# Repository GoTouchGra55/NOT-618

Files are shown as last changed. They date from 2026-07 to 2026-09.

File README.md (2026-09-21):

# NOT-618

_A custom CoreXY printer built on hopes and dreams._

   

**New Object Transmitter-618 / NOT-618** is a medium sized print volume _(220 × 220 × 220 mm)_ custom CoreXY 3d printer developed as a long term engineering project.

The project focuses on reliability, serviceability, and my open-source loyalty while serving as a platform for learning embedded systems, mechanical & PCB design, and firmware engineering.

## Features

- Automatic bed-leveling using BLTouch
- Independent dual Z motors
- Custom STM32F407-based controller (Vulcan-MK1)
- Marlin firmware support
- Fully open source design
- 24V power input

## Mechanical Design

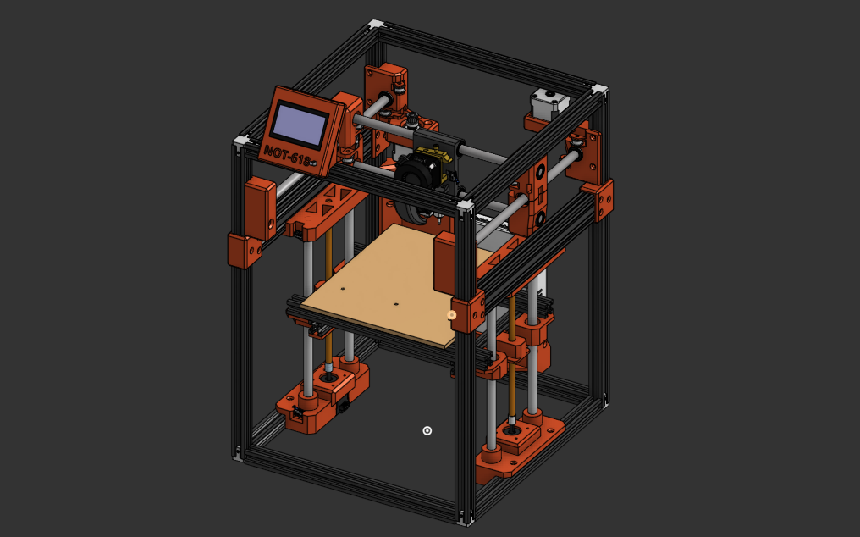
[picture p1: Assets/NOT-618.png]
NOT-618


### CAD: [OnShape URL](https://cad.onshape.com/documents/e82edfc86bb0a1665cdc75ee/w/ca3abfddd82f0954c06884bb/e/6fbd4bded61cf9b65a4d5030)

## PCB Design _(Vulcan-MK1)_

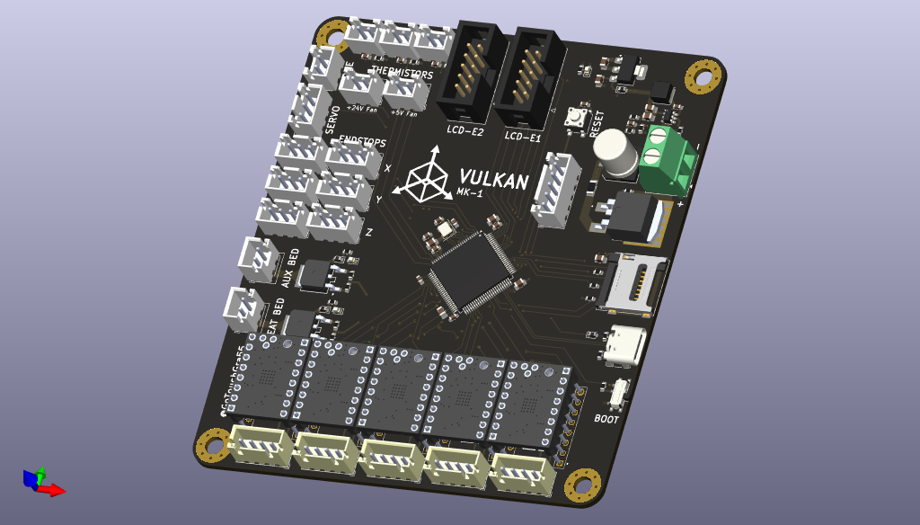
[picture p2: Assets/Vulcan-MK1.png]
Vulcan-MK1


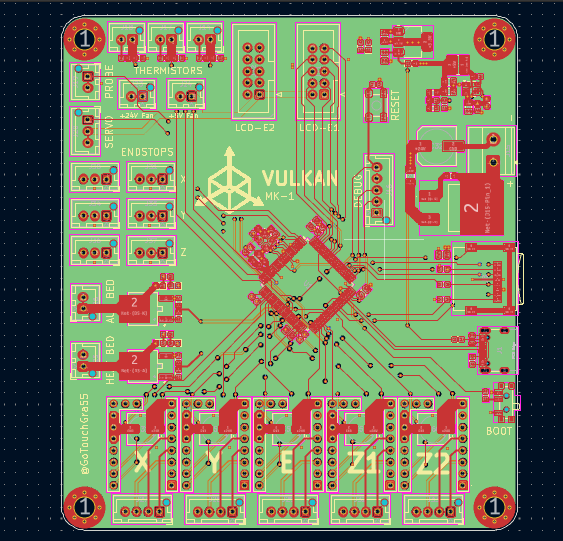
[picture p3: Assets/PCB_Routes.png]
Vulcan-MK1 Routes


For GERBER file see [Vulcan-MK1](PCB/production/Vulcan-MK1.zip)

## Schematics

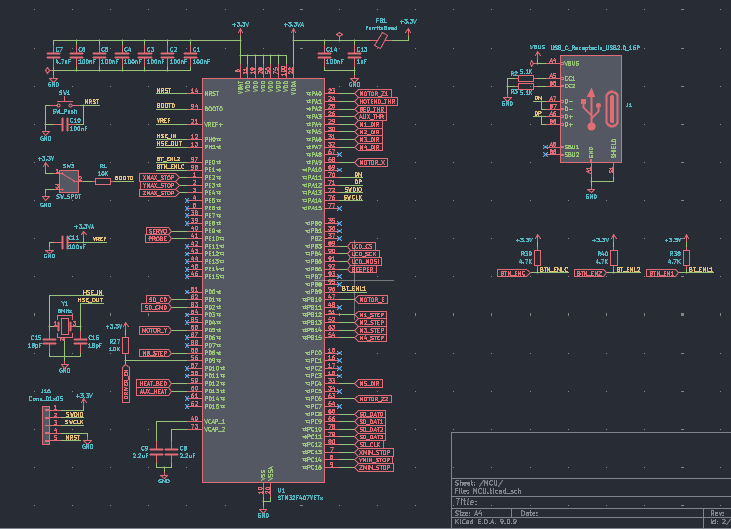
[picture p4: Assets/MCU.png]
MCU

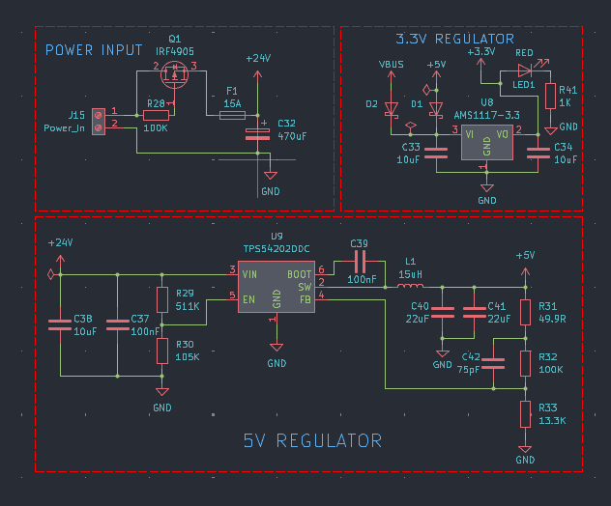
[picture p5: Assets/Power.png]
POWER

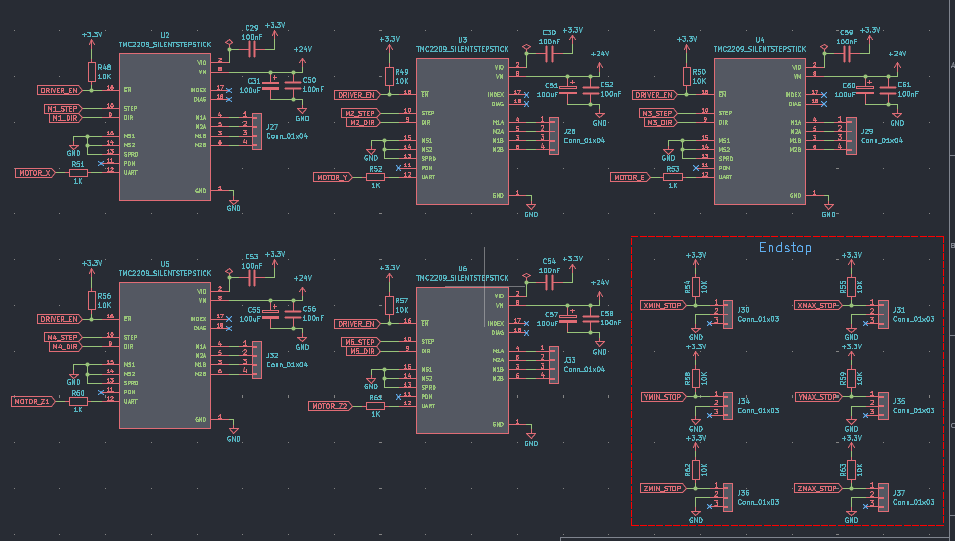
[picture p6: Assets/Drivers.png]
Drivers

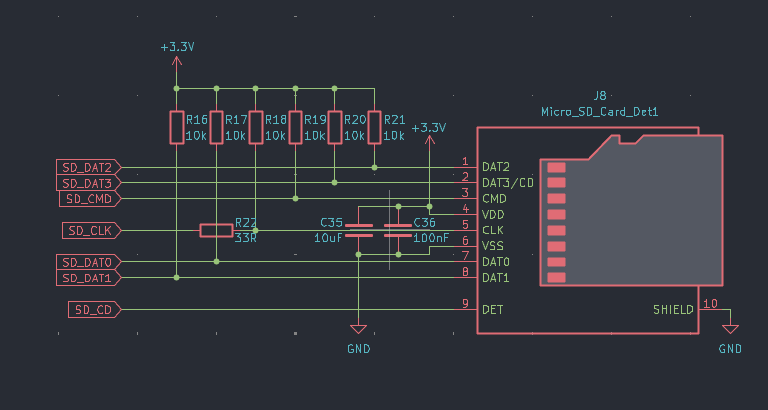
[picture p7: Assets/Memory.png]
Memory

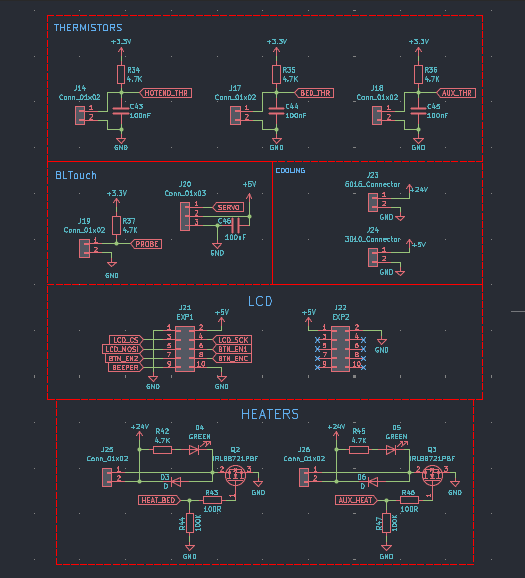
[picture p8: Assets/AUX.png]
Aux


## Specifications

| Component | Specification |
| --- | --- |
| Motion System | CoreXY |
| Build Volume | 220 × 220 × 220 mm |
| MCU | STM32F407VET6 |
| Stepper Drivers | TMC2209 |
| Hotend | E3D V6 |
| Heated Bed | Anycubic Kobra Go 24V |
| Bed Probe | BLTouch |
| Power Supply | 24V 15A |
| Cooling | 5015 Part Cooling + 3010 Hotend Fan |

## Assembly guide

1. Refer to the Onshape assembly for component placement and assembly order.
2. Do not carelessly wire the pcb and ensure good solder joints.

## ⚠️ Warning

1. Double-check polarity of capacitors and power input before powering the board. Otherwise you've made a fancy bomb :D
2. Use a 24v 15A SMPS for optimal performance. NEVER go higher than this.

## Flashing the Firmware

### 1. Build the Firmware

Compile Marlin using PlatformIO:

```bash
pio run -e STM32F407VE_black
```

After a successful build, the firmware will be located at:

```
.pio/build/STM32F407VE_black/firmware.bin
```

---

### 2. Copy the Firmware

1. Insert a microSD card (FAT32 formatted).
2. Copy `firmware.bin` to the root directory of the SD card.

The directory should look like:

```
/
├── firmware.bin
```

### 3. Flash the Board

1. Turn **off** the printer.
2. Insert the microSD card into the onboard SD card slot.
3. Power the board.

The STM32 bootloader will automatically detect `firmware.bin` and begin flashing.

Do **not** remove power during this process.

---

### 4. Verify the Flash

After flashing is complete:

- The board should boot into Marlin.
- Connect to the USB serial port.
- Send:

```gcode
M115
```

A successful response should report the installed Marlin version.

## Bill of Materials

| Name | Purpose | Quantity | Total Cost (USD) | Distributor |
| --- | --- | ---: | ---: | --- |
| Zip Ties | Cable management | 1 | $1.04 | Daraz Nepal |
| 22 AWG Wire | For long connections | 1 | $4.08 | Daraz Nepal |
| 18 AWG Wire | For power connections | 1 | $5.34 | Daraz Nepal |
| 24V 15A SMPS | For power delivery | 1 | $31.14 | Daraz Nepal |
| 0603 resistors | For PCB | 1 | $4.58 | Daraz Nepal |
| 0805 capacitors | For PCB | 1 | $5.78 | Daraz Nepal |
| Pitch Connectors | For PCB | 1 | $6.12 | Daraz Nepal |
| JST XH Connectors | For PCB | 1 | $5.11 | Daraz Nepal |
| 5015 24V Fan | For cooling duct | 1 | $5.27 | Daraz Nepal |
| Screws | For securing connections | 1 | $11.78 | Daraz Nepal |
| 24V Heated Bed | For printer | 1 | $19.78 | Daraz Nepal |
| PEI Sheet | For printer | 1 | $13.52 | Daraz Nepal |
| GT2 idler | For movement | 8 | $25.24 | Daraz Nepal |
| GT2 belt | For movement | 1 | $10.99 | Daraz Nepal |
| E3D Hotend | For printing | 1 | $11.05 | Daraz Nepal |
| Timing belt fixer | For attaching belts | 1 | $3.1 | Daraz Nepal |
| T-Nuts | For attaching extrusions | 1 | $5.84 | Daraz Nepal |
| MK8 Extruder | For filament output | 1 | $12.14 | Daraz Nepal |
| Pancake Stepper | For MK8 extruder | 1 | $12.04 | Daraz Nepal |
| 3015 Fan | For hotend cooling | 1 | $3.14 | Daraz Nepal |
| Brass Inserts | For fasteners | 1 | $8.89 | Daraz Nepal |
| Allen Keys | For securing hex nuts | 1 | $1.75 | Daraz Nepal |
| Limit switches | For min-max feedback | 2 | $3.92 | Daraz Nepal |
| Motor Coupler | For attaching steppers and rods | 2 | $2.44 | Daraz Nepal |
| Threaded Rods | For Z-axis movement | 2 | $7.54 | Daraz Nepal |
| GT2 pulley | For steppers | 2 | $1.57 | Daraz Nepal |
| Stepper Motors | For movement | 4 | $51.95 | Daraz Nepal |
| LM10UU Bearings | For linear movement | 8 | $18.49 | Daraz Nepal |
| LM12UU Bearings | For linear movement | 4 | $11.99 | Daraz Nepal |
| Linear Shaft (300mm) | For linear movement (12mm) | 4 | $67.98 | Daraz Nepal |
| Linear Shaft (500mm) | For linear movement (10mm) | 2 | $27.06 | Daraz Nepal |
| Linear Shaft (330mm) | For linear movement (10mm) | 2 | $19.10 | Daraz Nepal |
| BLTouch | For auto-bed leveling | 1 | $12.74 | Daraz Nepal |
| 2040 Extrusion | For printer stability | 1 | $15 | Daraz Nepal |
| 2020 Extrusion (800mm) | Printer frame | 5 | $117.08 | Daraz Nepal |
| 2020 Extrusion (600mm) | Printer frame | 5 | $104.98 | Daraz Nepal |
| TMC2209 drivers | To drive motors | 5 | $37.26 | Daraz Nepal |
| 12864 LCD | To display stuff | 1 | $35.39 | Daraz Nepal |
| 3-Way Connector | To connect corners of extrusion | 8 | $17.53 | Daraz Nepal |
| Vulcan-MK1 PCB | To control printer | 1 | $151.24 | JLCPCB |
| **Shipping** | | | **$29.72** | **Daraz Nepal & JLCPCB** |
| **Total** | | | **$944.16** | |

## License

### MIT-License - See [LICENSE](/LICENSE)

## Author 🧑‍💻

### [Shaurya Tamang](https://shauryatamang.netlify.app/)

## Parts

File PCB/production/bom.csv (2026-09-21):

Designator | Footprint | Quantity | Value | LCSC Part #
C1, C10, C11, C12, C14, C18, C2, C29, C3, C30, C36, C4, C43, C44, C45, C46, C5, C50, C52, C53, C54, C56, C58, C59, C6, C61 | 0603 | 26 | 100nF
C13 | 0805 | 1 | 1uF
C15, C16 | 0603 | 2 | 18pF
C17, C33, C34, C35 | 0805 | 4 | 10uF
C19, C20 | 0805 | 2 | 22uF
C21 | 0603 | 1 | 75pF
C31, C51, C55, C57, C60 | CP_Elec_6.3x7.7 | 5 | 100uF
C32 | C_Elec_8x10.2 | 1 | 470uF
C7 | 0805 | 1 | 4.7uF
C8, C9 | 0805 | 2 | 2.2uF
D1, D2 | 0603 | 2 | D_Schottky
D3, D6 | 0603 | 2 | D
D4, D5 | 0603 | 2 | GREEN
F1 | 1206 | 1 | 15A
FB1 | 0603 | 1 | FerriteBead
J1 | USB_C_Receptacle_GCT_USB4105-xx-A_16P_TopMnt_Horizontal | 1 | USB_C_Receptacle_USB2.0_16P
J14, J17, J18, J19, J25, J26 | JST_XH_B2B-XH-AM_1x02_P2.50mm_Vertical | 6 | Conn_01x02
J15 | TerminalBlock_Phoenix_MKDS-1,5-2-5.08_1x02_P5.08mm_Horizontal | 1 | Power_In
J16 | JST_XH_B5B-XH-AM_1x05_P2.50mm_Vertical | 1 | Conn_01x05
J20, J30, J31, J34, J35, J36, J37 | JST_XH_B3B-XH-AM_1x03_P2.50mm_Vertical | 7 | Conn_01x03
J21 | IDC-Header_2x05_P2.54mm_Vertical | 1 | EXP1
J22 | IDC-Header_2x05_P2.54mm_Vertical | 1 | EXP2
J23 | JST_XH_B2B-XH-AM_1x02_P2.50mm_Vertical | 1 | 5015_Connector
J24 | JST_XH_B2B-XH-AM_1x02_P2.50mm_Vertical | 1 | 3010_Connector
J27, J28, J29, J32, J33 | JST_XH_B4B-XH-AM_1x04_P2.50mm_Vertical | 5 | Conn_01x04
J8 | microSD_HC_Wuerth_693072010801 | 1 | Micro_SD_Card_Det1
L1 | L_Cenker_CKCS4030 | 1 | 15uH
LED1 | 0603 | 1 | RED
Q1 | TRANS_IRF3205S | 1 | IRF4905
Q2, Q3 | TO252_AOS | 2 | IRLB8721PBF
R1, R16, R17, R18, R19, R20, R21, R27, R48, R49, R50, R54, R55, R56, R57, R58, R59, R62, R63 | 0603 | 19 | 10K
R2, R3 | 0603 | 2 | 5.1K
R22 | 0603 | 1 | 33R
R28, R44, R47, R7 | 0603 | 4 | 100K
R34, R35, R36, R37, R38, R39, R40, R42, R45 | 0603 | 9 | 4.7K
R4 | 0603 | 1 | 511K
R41, R51, R52, R53, R60, R61 | 0603 | 6 | 1K
R43, R46 | 0603 | 2 | 100R
R5 | 0603 | 1 | 105K
R6 | 0603 | 1 | 49.9R
R8 | 0603 | 1 | 13.3K
SW1 | SW_SPST_PTS647_Sx38 | 1 | SW_Push
SW3 | SW_SPDT_PCM12 | 1 | SW_SPDT
U1 | LQFP-100_14x14mm_P0.5mm | 1 | STM32F407VETx
U2, U3, U4, U5, U6 | MODULE_TMC2209_SILENTSTEPSTICK | 5 | TMC2209_SILENTSTEPSTICK
U7 | SOT-23-6 | 1 | TPS54202DDC
U8 | SOT-223-3_TabPin2 | 1 | AMS1117-3.3
Y1 | Crystal_SMD_3225-4Pin_3.2x2.5mm | 1 | 8MHz

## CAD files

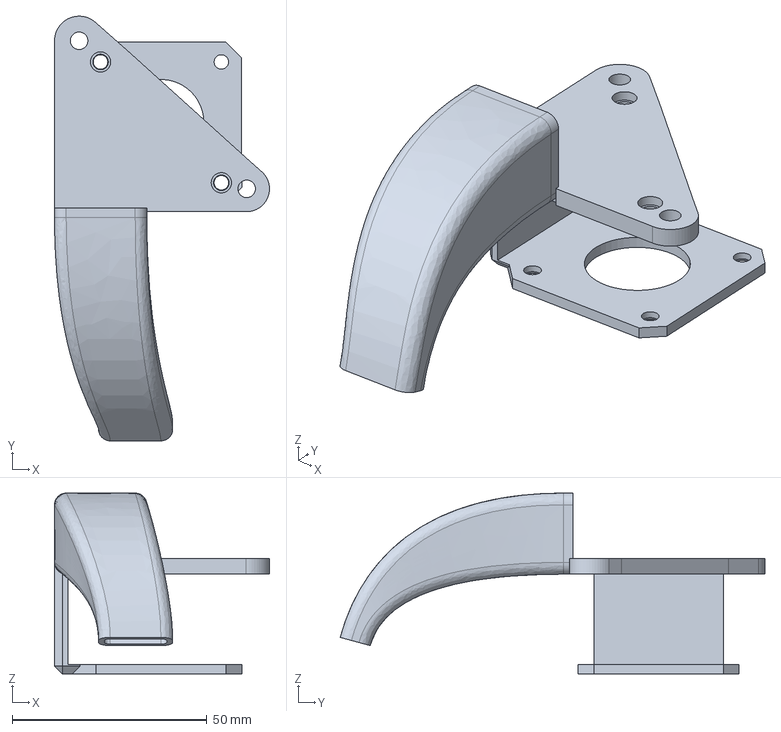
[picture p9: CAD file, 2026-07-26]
3d Files/STEP/NOT-618 - Duct Mount.step
55.2 x 109.0 x 46.4 mm

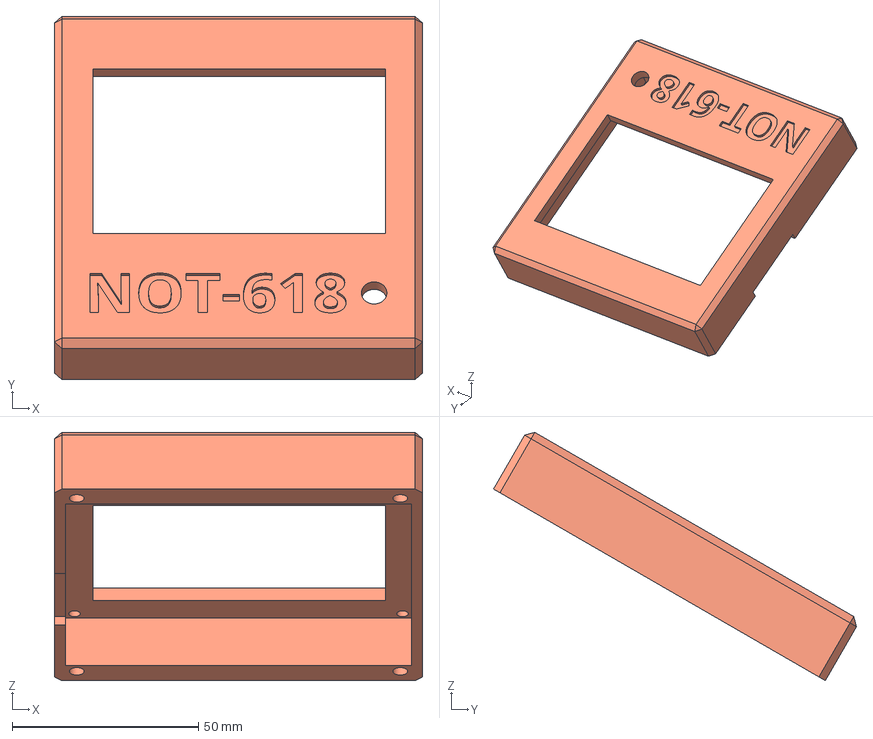
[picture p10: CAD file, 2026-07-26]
3d Files/STEP/NOT-618 - LCD Front.step
98.7 x 97.3 x 66.6 mm

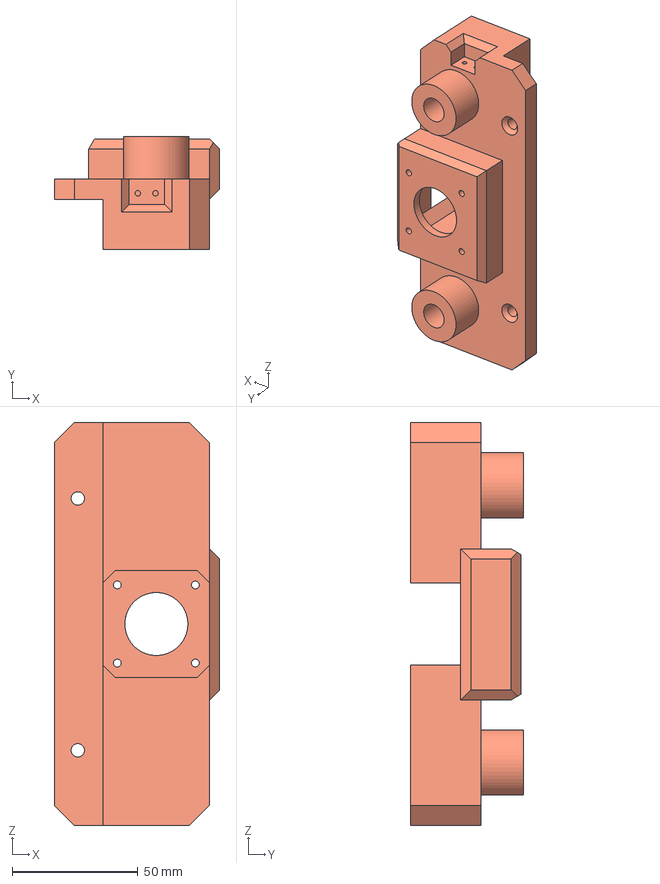
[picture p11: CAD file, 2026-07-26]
3d Files/STEP/NOT-618 - Z-BaseMount.step
65.7 x 45.0 x 160.0 mm

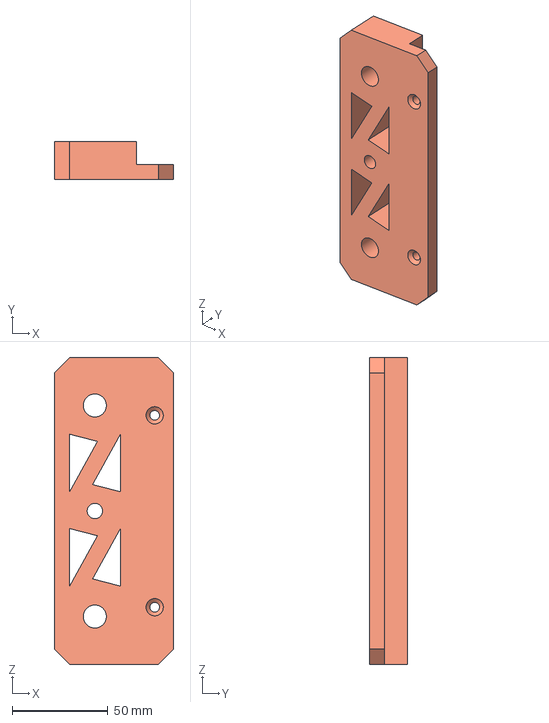
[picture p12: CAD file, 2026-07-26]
3d Files/STEP/NOT-618 - Z-TopMount.step
62.3 x 20.0 x 160.0 mm

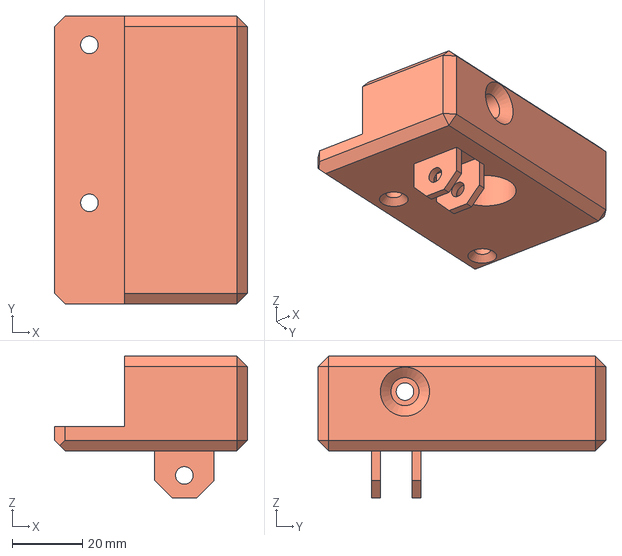
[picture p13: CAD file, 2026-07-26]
3d Files/STEP/NOT-618 - TFL-Rod Mount.step
55.0 x 82.0 x 40.4 mm

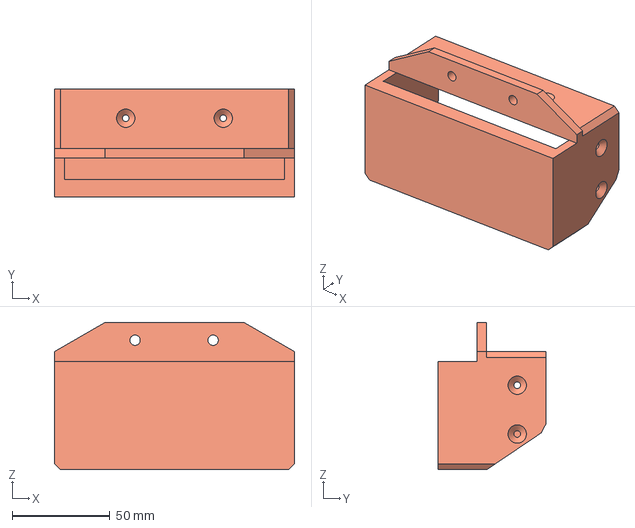
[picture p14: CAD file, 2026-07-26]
3d Files/STEP/NOT-618 - SMPS_Holder.step
123.0 x 55.4 x 75.5 mm

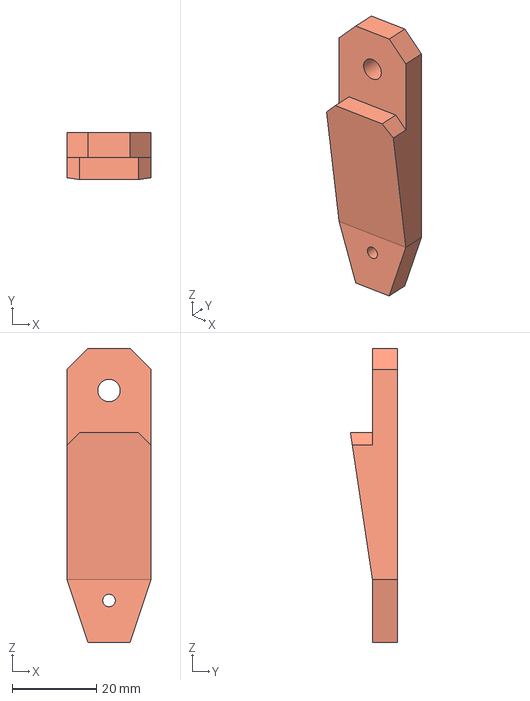
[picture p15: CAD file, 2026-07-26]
3d Files/STEP/NOT-618 - Bed Adapter.step
20.0 x 11.2 x 70.0 mm

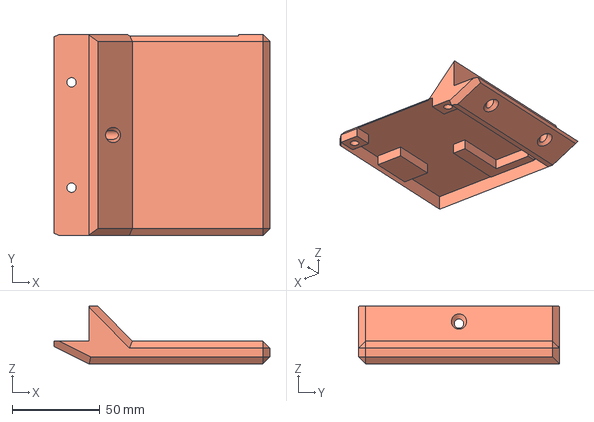
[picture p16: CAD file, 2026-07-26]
3d Files/STEP/NOT-618 - PCB_Holder.step
123.0 x 114.5 x 33.0 mm

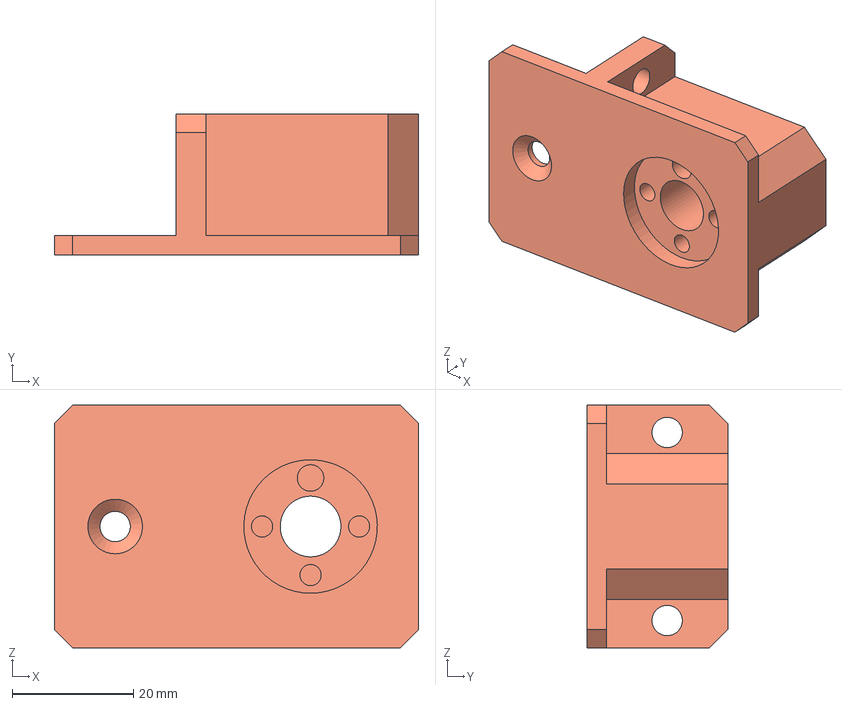
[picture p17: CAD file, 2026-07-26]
3d Files/STEP/NOT-618 - Lead Adapter.step
60.0 x 23.2 x 40.0 mm

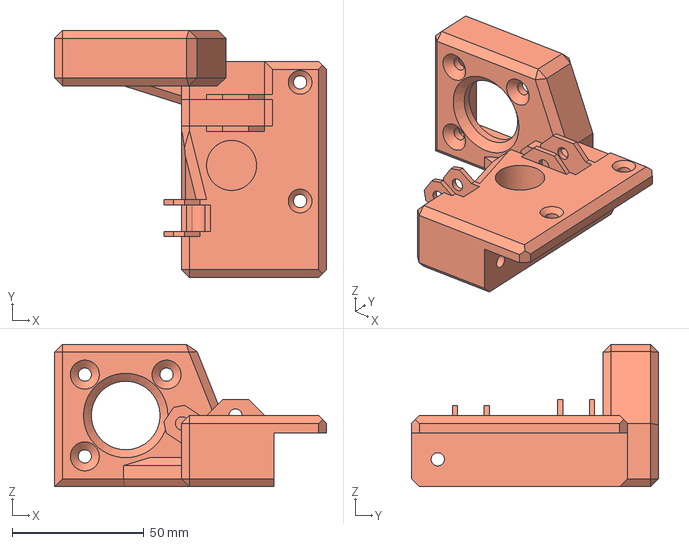
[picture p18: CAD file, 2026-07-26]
3d Files/STEP/NOT-618 - TBR-Rod Mount.step
103.1 x 93.8 x 54.0 mm

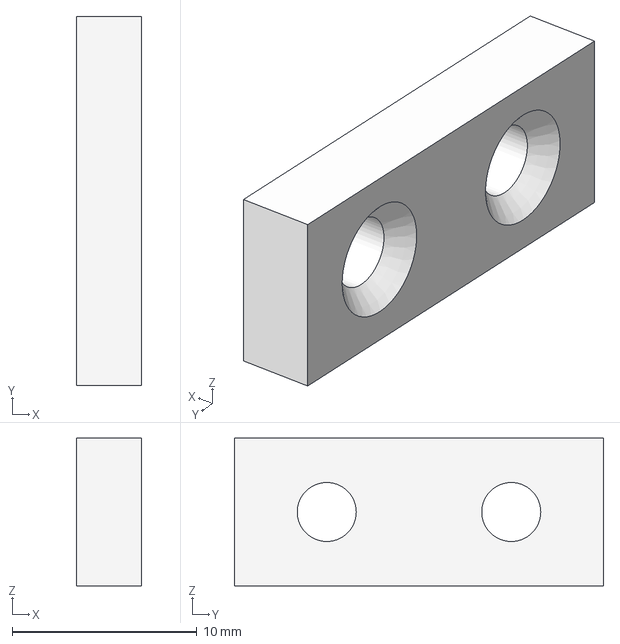
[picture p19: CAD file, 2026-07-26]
3d Files/STEP/NOT-618 - XY Mount.step
3.50 x 20.0 x 8.00 mm

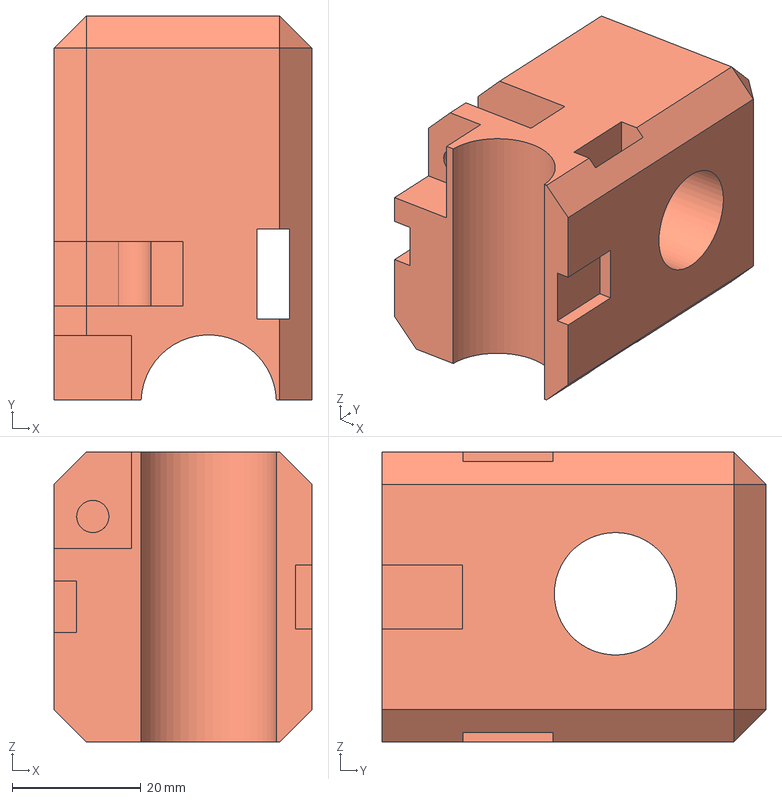
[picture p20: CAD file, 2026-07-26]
3d Files/STEP/NOT-618 - XY1_TOP.step
40.0 x 59.6 x 45.0 mm

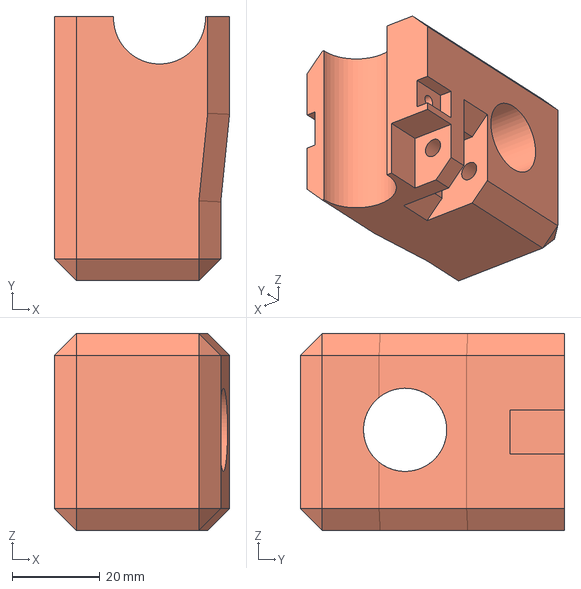
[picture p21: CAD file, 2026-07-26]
3d Files/STEP/NOT-618 - XY1_BOT.step
40.0 x 60.4 x 45.0 mm

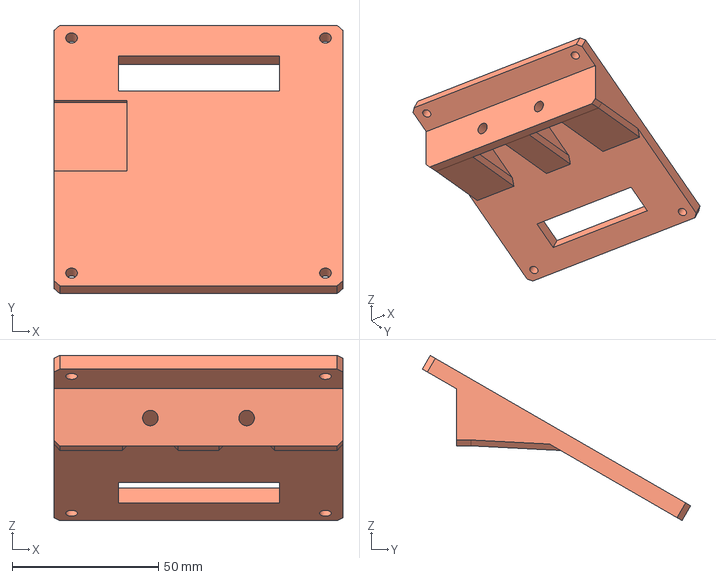
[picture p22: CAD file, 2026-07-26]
3d Files/STEP/NOT-618 - LCD Back.step
98.7 x 91.7 x 56.4 mm

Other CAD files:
3d Files/STEP/NOT-618 - Extruder Mount.step
3d Files/STEP/NOT-618 - XY2_BOT.step
3d Files/STEP/NOT-618 - TFR-Rod Mount.step
3d Files/STEP/NOT-618 - Ext Connector.step
3d Files/STEP/NOT-618 - Bearing Mount.step
3d Files/STEP/NOT-618 - Bed Adapter (1).step
3d Files/STEP/NOT-618 - Bed Adapter (2).step
3d Files/STEP/NOT-618 - Bed Adapter (3).step
3d Files/STEP/NOT-618 - Ext Connector (1).step
3d Files/STEP/NOT-618 - Ext Connector (2).step
3d Files/STEP/NOT-618 - Ext Connector (3).step
3d Files/STEP/NOT-618 - Lead Adapter (1).step
3d Files/STEP/NOT-618 - Linear Adapter (1).step
3d Files/STEP/NOT-618 - Linear Adapter (2).step
3d Files/STEP/NOT-618 - Linear Adapter (3).step
3d Files/STEP/NOT-618 - Linear Adapter.step
3d Files/STEP/NOT-618 - TBL-Rod Mount.step
3d Files/STEP/NOT-618 - XY Mount (1).step
3d Files/STEP/NOT-618 - XY2_TOP.step
3d Files/STEP/NOT-618 - Z-BaseMount (1).step
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

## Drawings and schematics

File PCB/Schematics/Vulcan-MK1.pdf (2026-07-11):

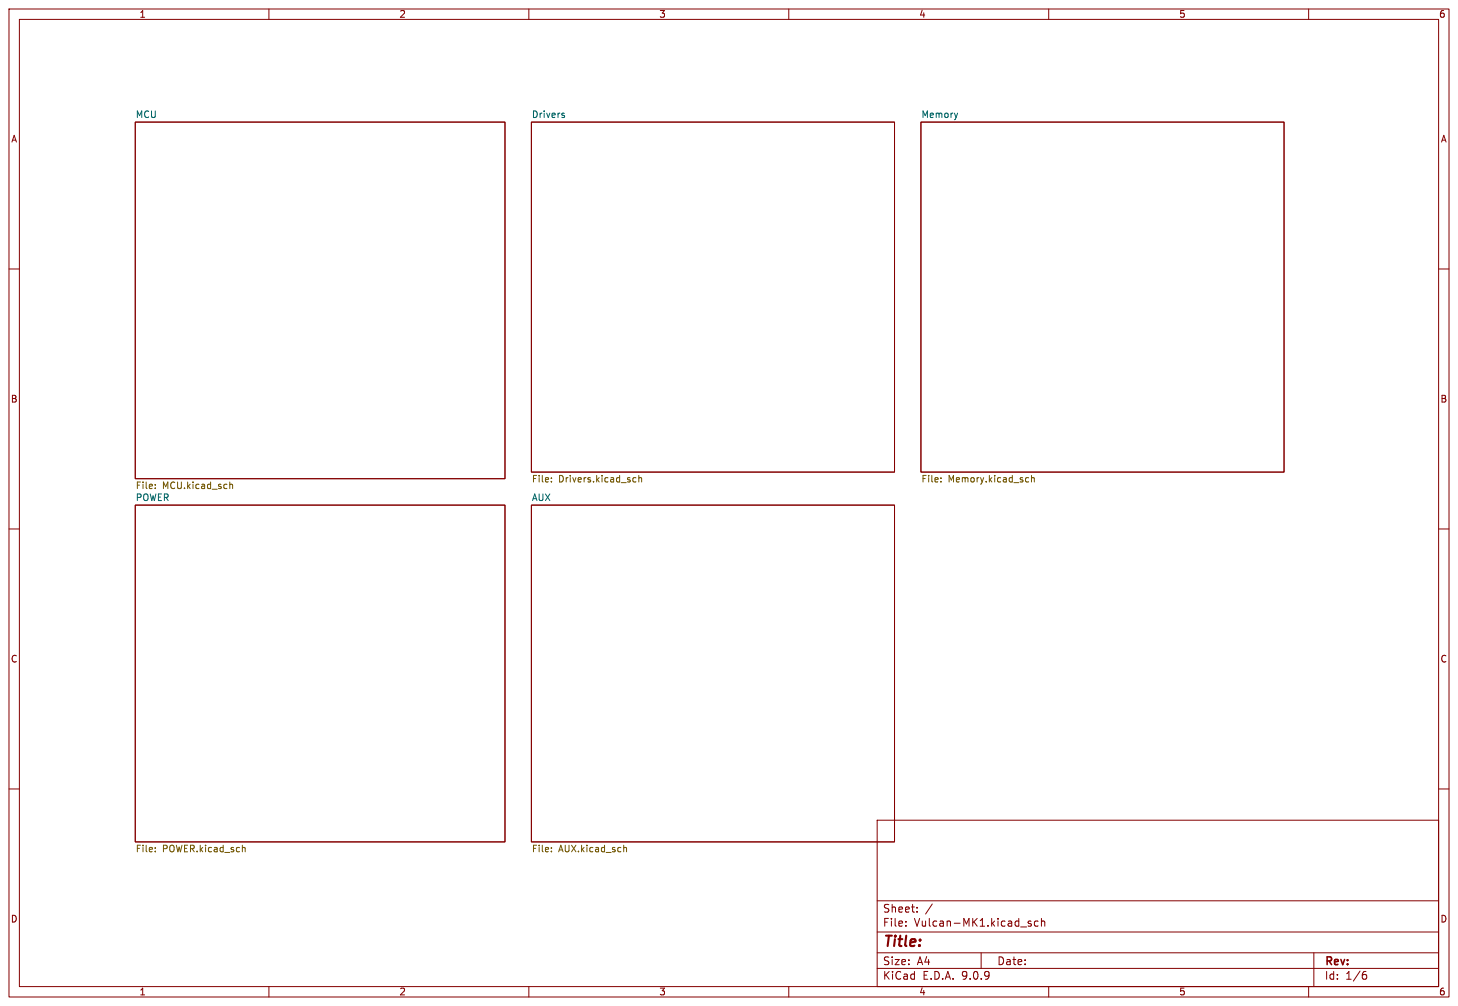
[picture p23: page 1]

Id: 1/6 Title: File: Vulcan-MK1.kicad_sch Sheet: /

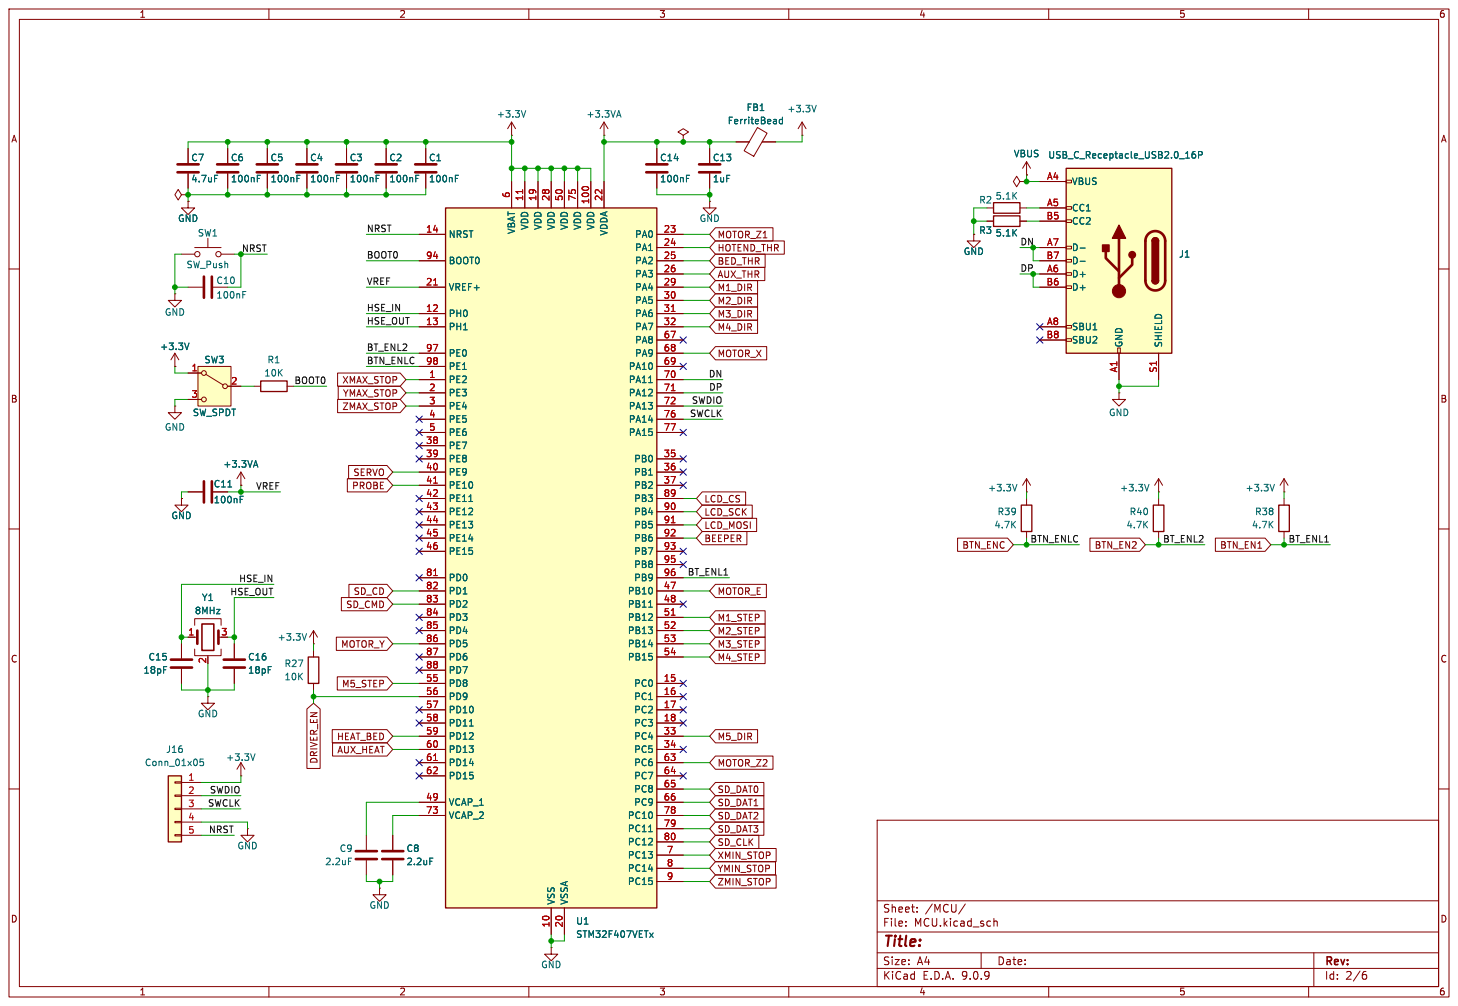
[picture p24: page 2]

Id: 2/6 Title: File: MCU.kicad_sch Sheet: /MCU/

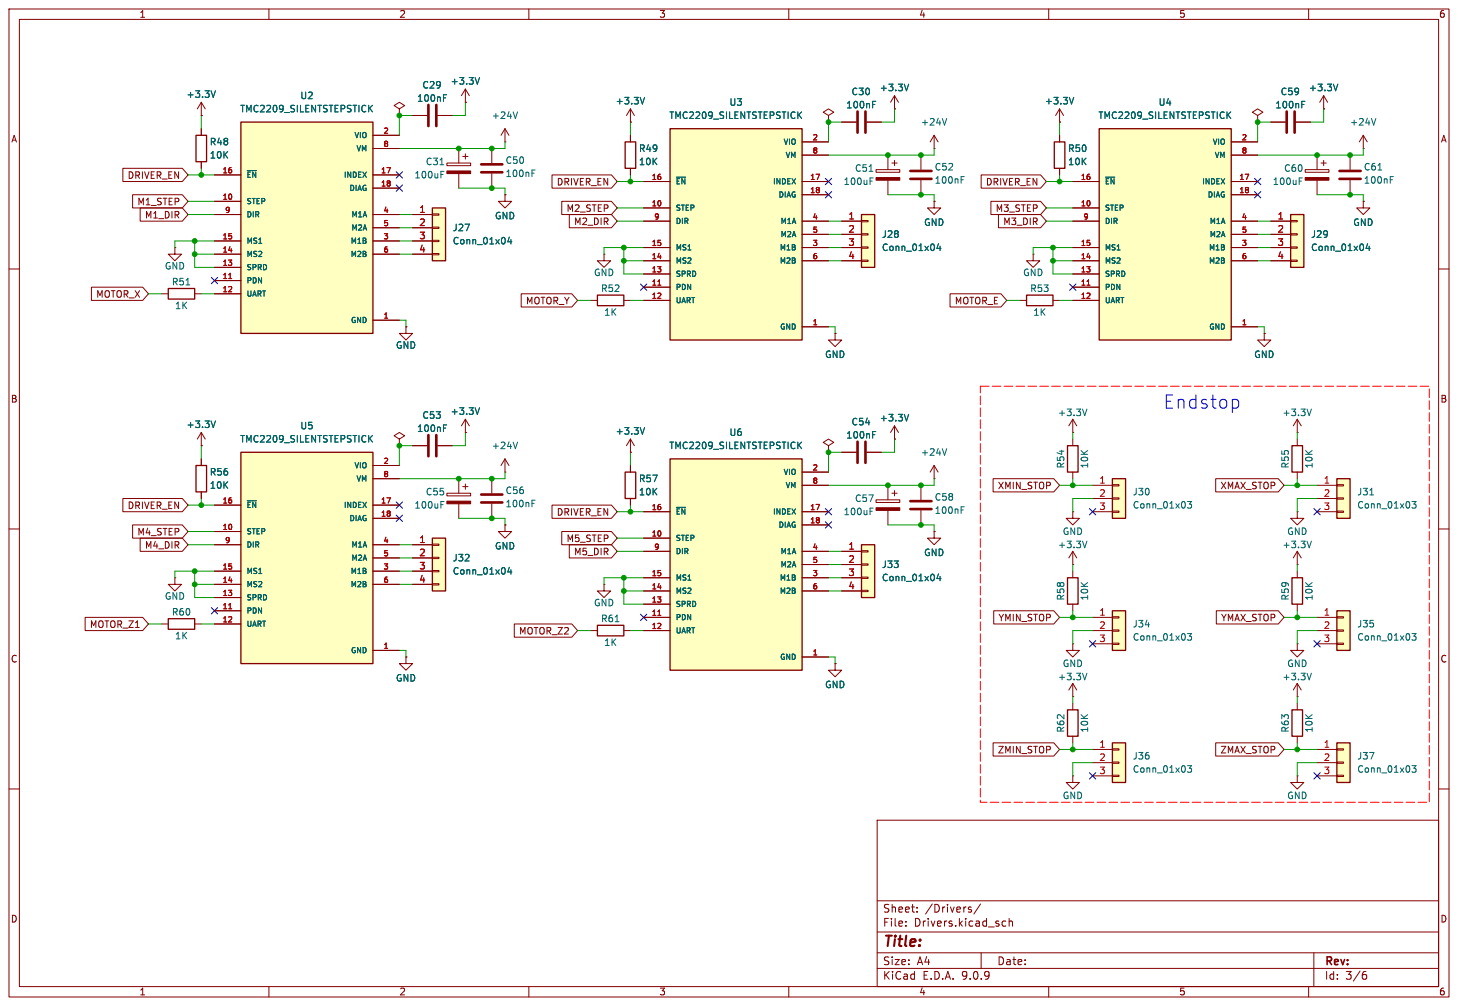
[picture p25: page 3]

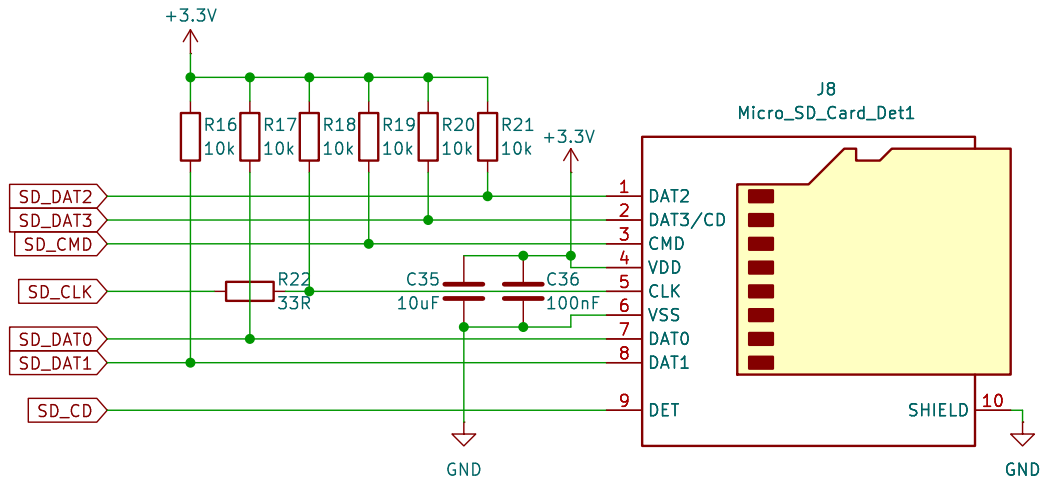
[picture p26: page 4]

Id: 4/6 Title: File: Memory.kicad_sch Sheet: /Memory/ GND

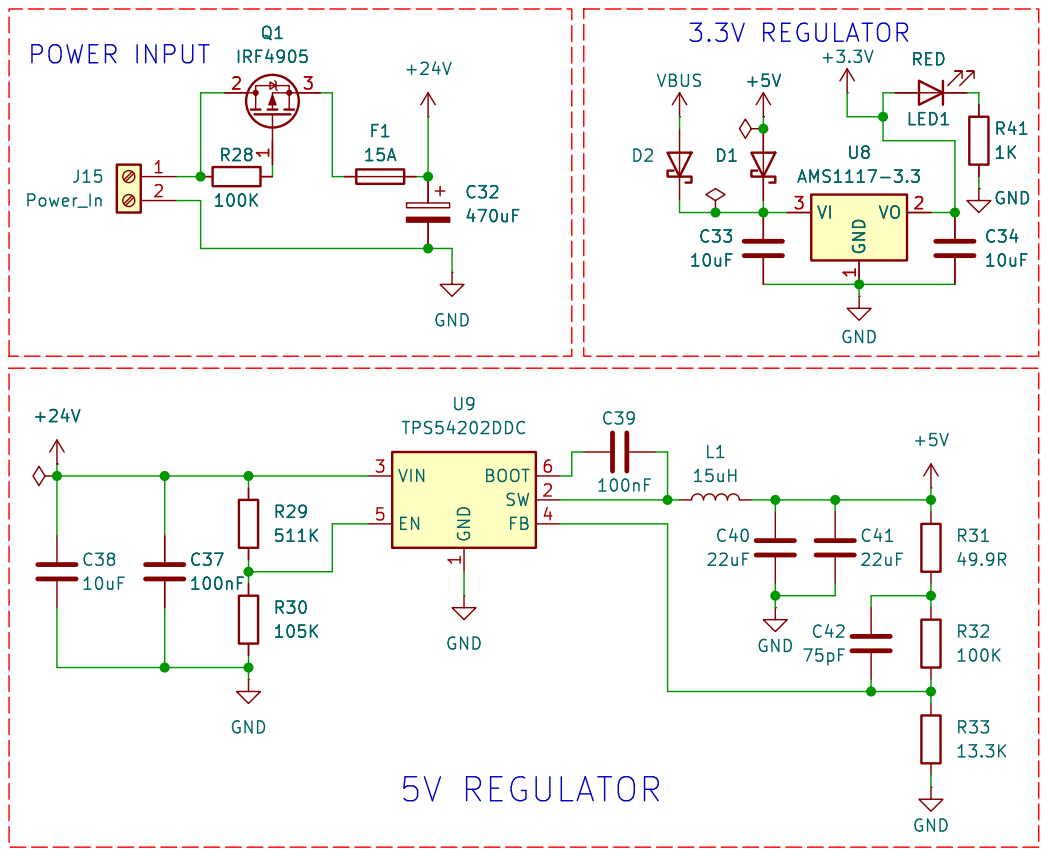
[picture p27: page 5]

Id: 5/6 Title: File: POWER.kicad_sch Sheet: /POWER/

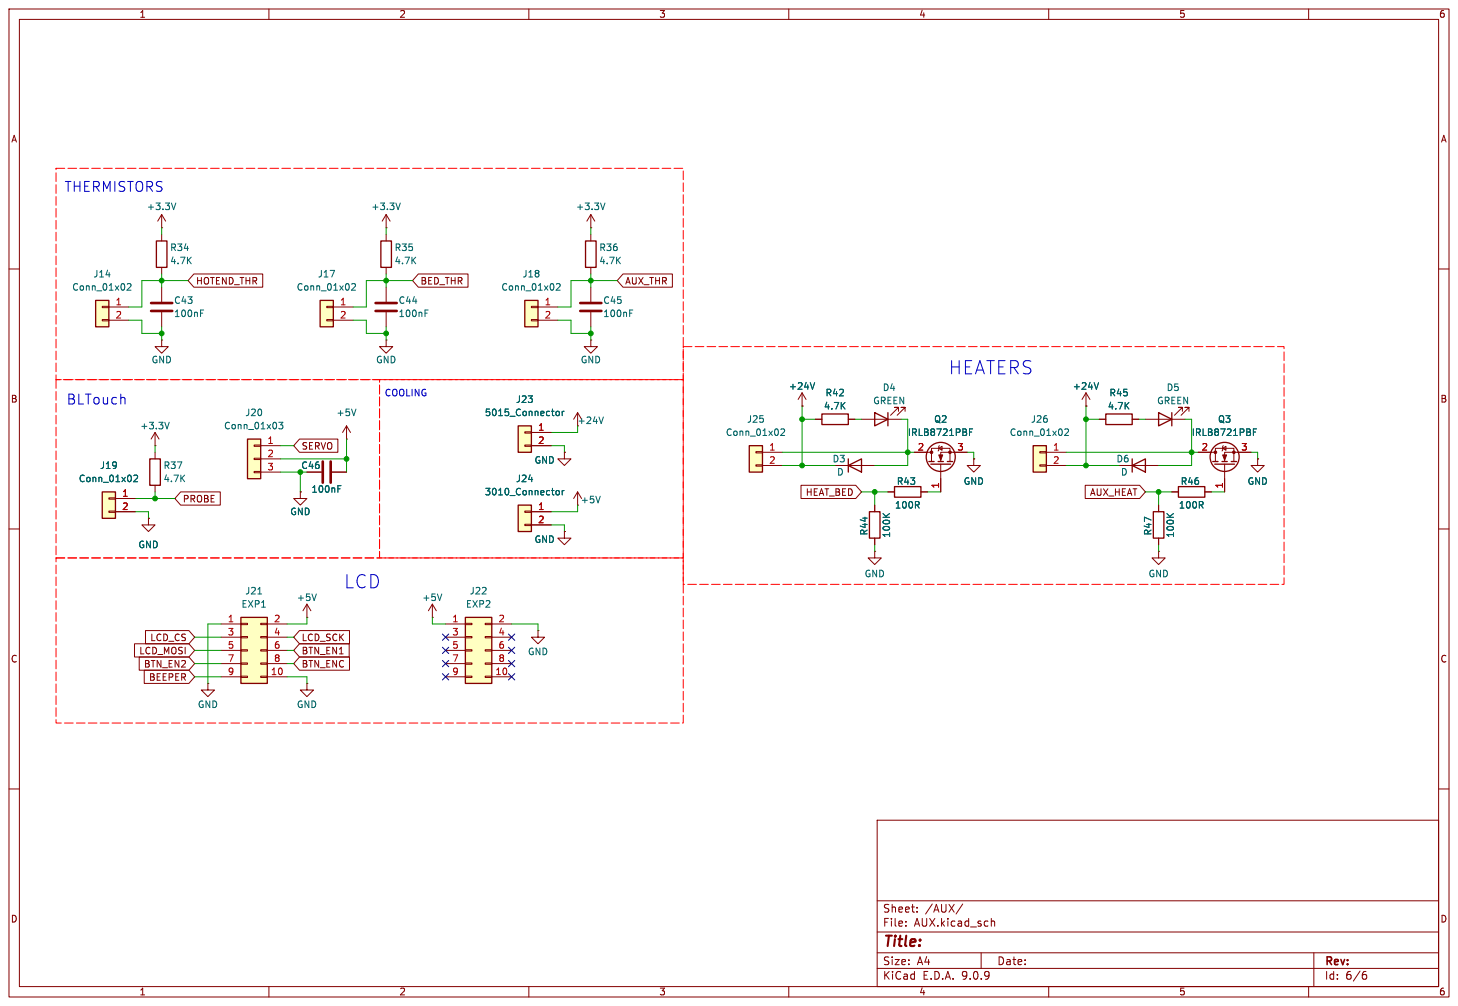
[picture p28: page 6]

Id: 6/6 Title: File: AUX.kicad_sch Sheet: /AUX/ R37
BTN_EN1 PROBE

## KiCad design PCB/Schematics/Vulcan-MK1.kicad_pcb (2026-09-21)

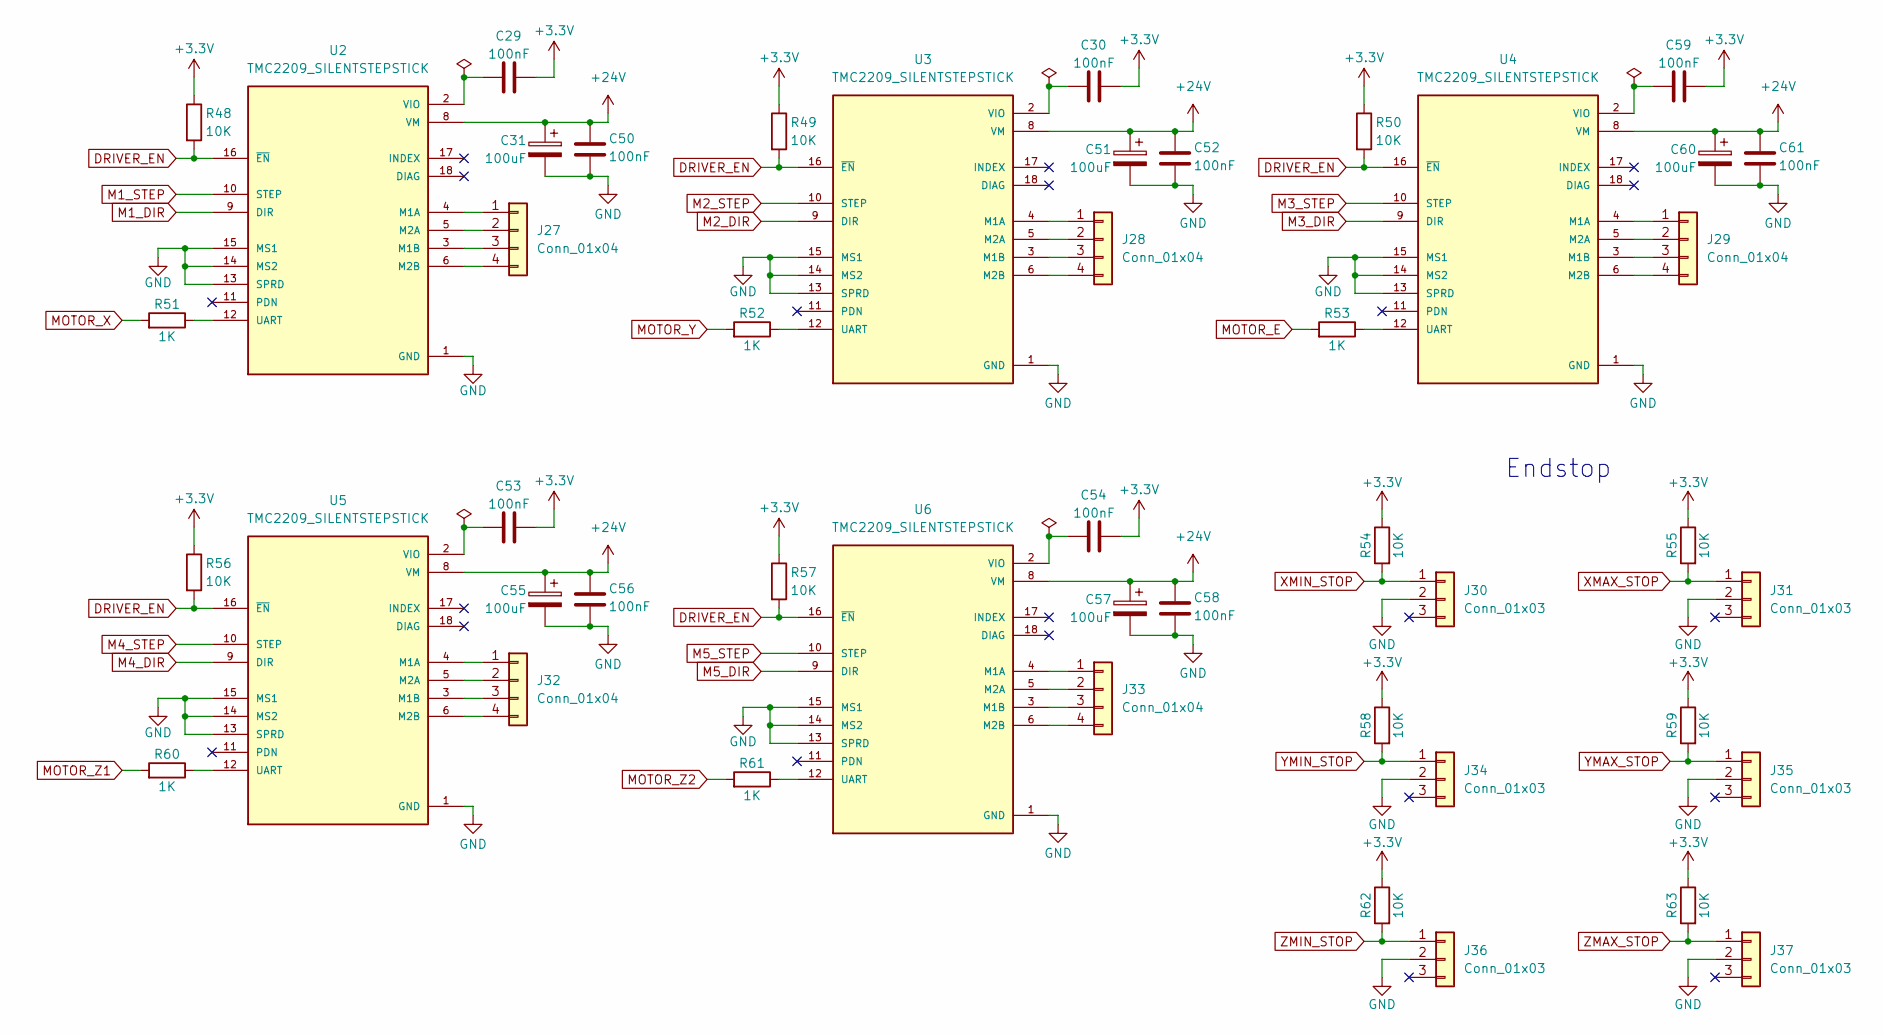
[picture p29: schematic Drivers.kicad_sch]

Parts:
C29, C30, C50, C52, C53, C54, C56, C58, C59, C61: 100nF; C_0603_1608Metric
C31, C51, C55, C57, C60: 100uF; CP_Elec_6.3x7.7
J27, J28, J29, J32, J33: Conn_01x04; JST_XH_B4B-XH-AM_1x04_P2.50mm_Vertical
J30, J31, J34, J35, J36, J37: Conn_01x03; JST_XH_B3B-XH-AM_1x03_P2.50mm_Vertical
R48, R49, R50, R54, R55, R56, R57, R58, R59, R62, R63: 10K; R_0603_1608Metric
R51, R52, R53, R60, R61: 1K; R_0603_1608Metric
U2, U3, U4, U5, U6: TMC2209_SILENTSTEPSTICK; MODULE_TMC2209_SILENTSTEPSTICK; PARTREV 1.20

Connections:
+3.3V: C29.1, C30.1, C53.1, C54.1, C59.1, R48.1, R49.1, R50.1, R54.1, R55.1, R56.1, R57.1, R58.1, R59.1, R62.1, R63.1; also elsewhere on the board
+24V: C31.1, C50.1, C51.1, C52.1, C55.1, C56.1, C57.1, C58.1, C60.1, C61.1, U2.8 (VM), U3.8 (VM), U4.8 (VM), U5.8 (VM), U6.8 (VM); also elsewhere on the board
DRIVER_EN: R48.2, R49.2, R50.2, R56.2, R57.2, U2.16 (~EN), U3.16 (~EN), U4.16 (~EN), U5.16 (~EN), U6.16 (~EN); also elsewhere on the board
GND: C31.2, C50.2, C51.2, C52.2, C55.2, C56.2, C57.2, C58.2, C60.2, C61.2, J30.2, J31.2, J34.2, J35.2, J36.2, J37.2, U2.1 (GND), U2.7 (GND), U2.13 (SPRD), U2.14 (MS2), U2.15 (MS1), U3.1 (GND), U3.7 (GND), U3.13 (SPRD), U3.14 (MS2), U3.15 (MS1), U4.1 (GND), U4.7 (GND), U4.13 (SPRD), U4.14 (MS2), U4.15 (MS1), U5.1 (GND), U5.7 (GND), U5.13 (SPRD), U5.14 (MS2), U5.15 (MS1), U6.1 (GND), U6.7 (GND), U6.13 (SPRD), U6.14 (MS2), U6.15 (MS1); also elsewhere on the board
M1_DIR: U2.9 (DIR); also elsewhere on the board
M1_STEP: U2.10 (STEP); also elsewhere on the board
M2_DIR: U3.9 (DIR); also elsewhere on the board
M2_STEP: U3.10 (STEP); also elsewhere on the board
M3_DIR: U4.9 (DIR); also elsewhere on the board
M3_STEP: U4.10 (STEP); also elsewhere on the board
M4_DIR: U5.9 (DIR); also elsewhere on the board
M4_STEP: U5.10 (STEP); also elsewhere on the board
M5_DIR: U6.9 (DIR); also elsewhere on the board
M5_STEP: U6.10 (STEP); also elsewhere on the board
MOTOR_E: R53.2; also elsewhere on the board
MOTOR_X: R51.2; also elsewhere on the board
MOTOR_Y: R52.2; also elsewhere on the board
MOTOR_Z1: R60.2; also elsewhere on the board
MOTOR_Z2: R61.2; also elsewhere on the board
unnamed: J27.1, U2.4 (M1A)
unnamed: J27.2, U2.5 (M2A)
unnamed: J27.3, U2.3 (M1B)
unnamed: J27.4, U2.6 (M2B)
unnamed: J28.1, U3.4 (M1A)
unnamed: J28.2, U3.5 (M2A)
unnamed: J28.3, U3.3 (M1B)
unnamed: J28.4, U3.6 (M2B)
unnamed: J29.1, U4.4 (M1A)
unnamed: J29.2, U4.5 (M2A)
unnamed: J29.3, U4.3 (M1B)
unnamed: J29.4, U4.6 (M2B)
unnamed: J32.1, U5.4 (M1A)
unnamed: J32.2, U5.5 (M2A)
unnamed: J32.3, U5.3 (M1B)
unnamed: J32.4, U5.6 (M2B)
unnamed: J33.1, U6.4 (M1A)
unnamed: J33.2, U6.5 (M2A)
unnamed: J33.3, U6.3 (M1B)
unnamed: J33.4, U6.6 (M2B)
unnamed: R51.1, U2.12 (UART)
unnamed: C29.2, U2.2 (VIO)
unnamed: R52.1, U3.12 (UART)
unnamed: C30.2, U3.2 (VIO)
unnamed: R53.1, U4.12 (UART)
unnamed: C59.2, U4.2 (VIO)
unnamed: R60.1, U5.12 (UART)
unnamed: C53.2, U5.2 (VIO)
unnamed: R61.1, U6.12 (UART)
unnamed: C54.2, U6.2 (VIO)
XMAX_STOP: J31.1, R55.2; also elsewhere on the board
XMIN_STOP: J30.1, R54.2; also elsewhere on the board
YMAX_STOP: J35.1, R59.2; also elsewhere on the board
YMIN_STOP: J34.1, R58.2; also elsewhere on the board
ZMAX_STOP: J37.1, R63.2; also elsewhere on the board
ZMIN_STOP: J36.1, R62.2; also elsewhere on the board

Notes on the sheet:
Endstop

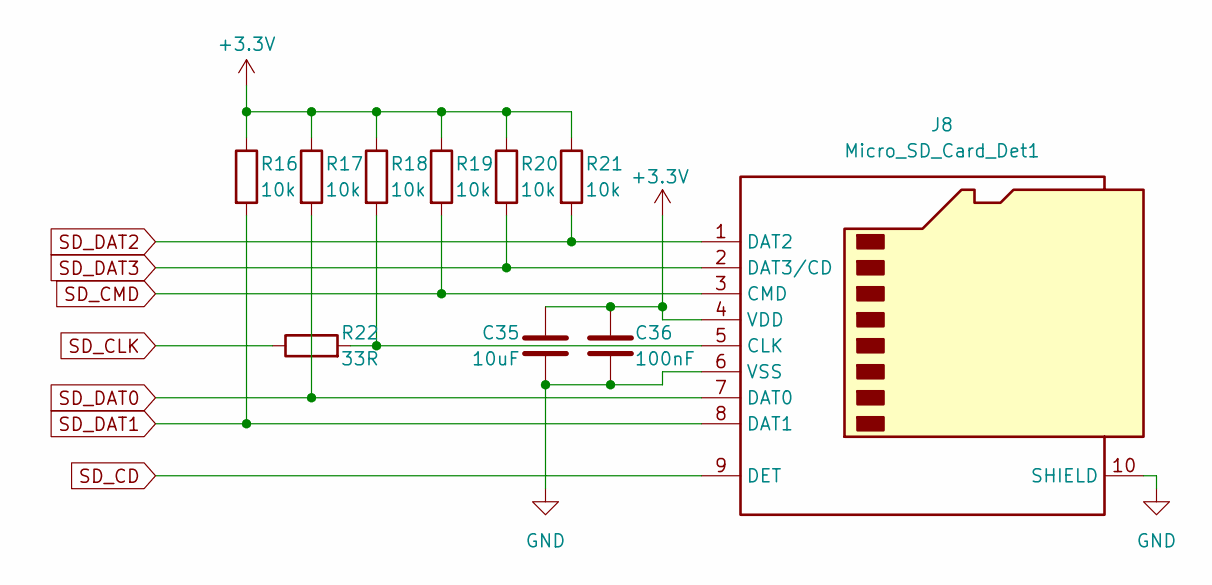
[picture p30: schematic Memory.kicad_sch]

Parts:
C35: 10uF; C_0805_2012Metric
C36: 100nF; C_0603_1608Metric
J8: Micro_SD_Card_Det1; microSD_HC_Wuerth_693072010801
R16, R17, R18, R19, R20, R21: 10k; R_0603_1608Metric
R22: 33R; R_0603_1608Metric

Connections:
+3.3V: C35.1, C36.1, J8.4 (VDD), R16.1, R17.1, R18.1, R19.1, R20.1, R21.1; also elsewhere on the board
GND: C35.2, C36.2, J8.6 (VSS), J8.10 (SHIELD); also elsewhere on the board
unnamed: J8.5 (CLK), R18.2, R22.2
SD_CD: J8.9 (DET); also elsewhere on the board
SD_CLK: R22.1; also elsewhere on the board
SD_CMD: J8.3 (CMD), R19.2; also elsewhere on the board
SD_DAT0: J8.7 (DAT0), R17.2; also elsewhere on the board
SD_DAT1: J8.8 (DAT1), R16.2; also elsewhere on the board
SD_DAT2: J8.1 (DAT2), R21.2; also elsewhere on the board
SD_DAT3: J8.2 (DAT3/CD), R20.2; also elsewhere on the board

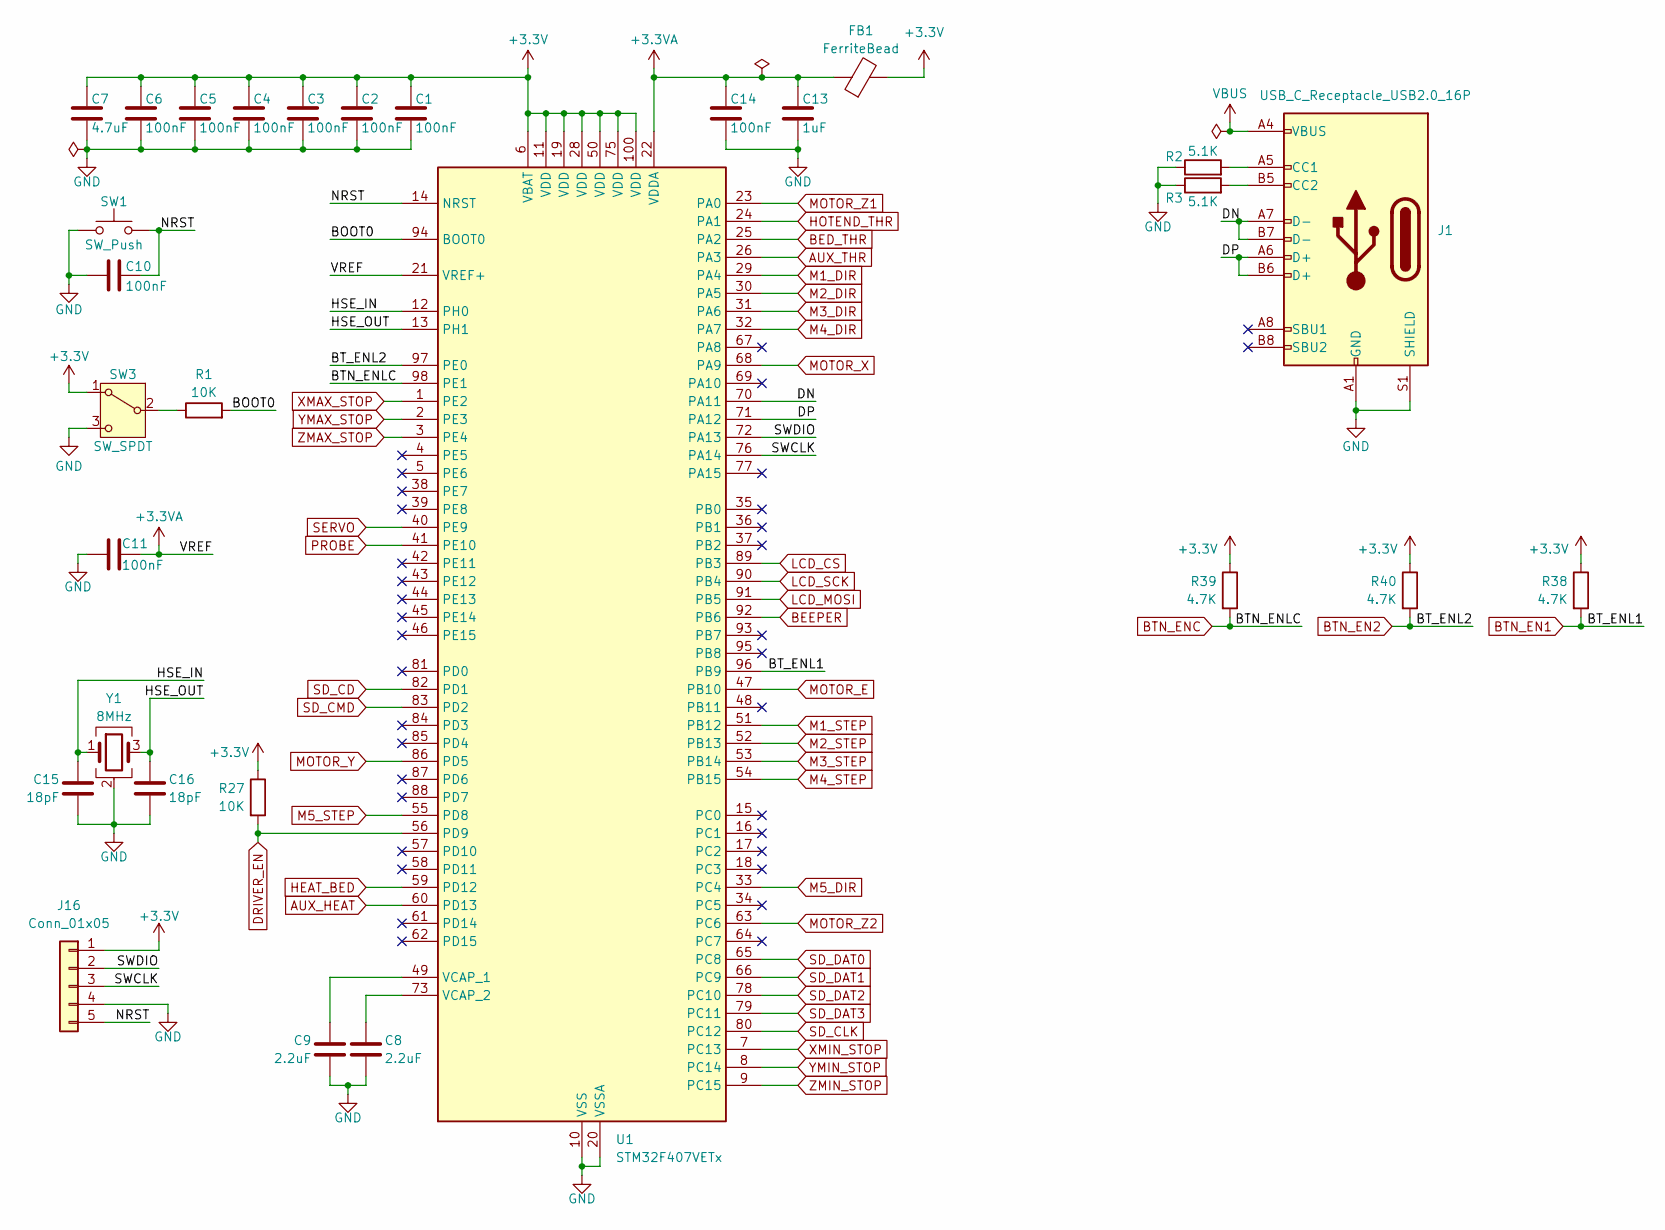
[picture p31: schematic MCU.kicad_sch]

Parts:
C1, C2, C3, C4, C5, C6, C10, C11, C14: 100nF; C_0603_1608Metric
C7: 4.7uF; C_0805_2012Metric
C8, C9: 2.2uF; C_0805_2012Metric
C13: 1uF; C_0805_2012Metric
C15, C16: 18pF; C_0603_1608Metric
FB1: FerriteBead; C_0603_1608Metric
J1: USB_C_Receptacle_USB2.0_16P; USB_C_Receptacle_GCT_USB4105-xx-A_16P_TopMnt_Horizontal
J16: Conn_01x05; JST_XH_B5B-XH-AM_1x05_P2.50mm_Vertical
R1, R27: 10K; R_0603_1608Metric
R2, R3: 5.1K; R_0603_1608Metric
R38, R39, R40: 4.7K; R_0603_1608Metric
SW1: SW_Push; SW_SPST_PTS647_Sx38
SW3: SW_SPDT; SW_SPDT_PCM12
U1: STM32F407VETx; LQFP-100_14x14mm_P0.5mm
Y1: 8MHz; Crystal_SMD_3225-4Pin_3.2x2.5mm

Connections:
+3.3V: C1.1, C2.1, C3.1, C4.1, C5.1, C6.1, C7.1, FB1.2, J16.1, R27.1, R38.1, R39.1, R40.1, SW3.1 (A), U1.6 (VBAT), U1.11 (VDD), U1.19 (VDD), U1.28 (VDD), U1.50 (VDD), U1.75 (VDD), U1.100 (VDD); also elsewhere on the board
+3.3VA: C11.2, C13.1, C14.1, FB1.1, U1.21 (VREF+), U1.22 (VDDA)
/MCU/BOOT0: R1.2, U1.94 (BOOT0)
/MCU/DN: J1.A7 (D-), J1.B7 (D-), U1.70 (PA11)
/MCU/DP: J1.A6 (D+), J1.B6 (D+), U1.71 (PA12)
/MCU/HSE_IN: C15.2, U1.12 (PH0), Y1.1
/MCU/HSE_OUT: C16.2, U1.13 (PH1), Y1.3
/MCU/NRST: C10.2, J16.5, SW1.2, U1.14 (NRST)
/MCU/SWCLK: J16.3, U1.76 (PA14)
/MCU/SWDIO: J16.2, U1.72 (PA13)
AUX_HEAT: U1.60 (PD13); also elsewhere on the board
AUX_THR: U1.26 (PA3); also elsewhere on the board
BED_THR: U1.25 (PA2); also elsewhere on the board
BEEPER: U1.92 (PB6); also elsewhere on the board
BTN_EN1: R38.2, U1.96 (PB9); also elsewhere on the board
BTN_EN2: R40.2, U1.97 (PE0); also elsewhere on the board
BTN_ENC: R39.2, U1.98 (PE1); also elsewhere on the board
DRIVER_EN: R27.2, U1.56 (PD9); also elsewhere on the board
GND: C1.2, C2.2, C3.2, C4.2, C5.2, C6.2, C7.2, C8.1, C9.1, C10.1, C11.1, C13.2, C14.2, C15.1, C16.1, J1.A1 (GND), J1.A12 (GND), J1.B1 (GND), J1.B12 (GND), J1.S1 (SHIELD), J16.4, R2.1, R3.1, SW1.1, SW3.3 (C), U1.10 (VSS), U1.20 (VSSA), U1.27 (VSS), U1.74 (VSS), U1.99 (VSS), Y1.2 (G), Y1.4 (G); also elsewhere on the board
HEAT_BED: U1.59 (PD12); also elsewhere on the board
HOTEND_THR: U1.24 (PA1); also elsewhere on the board
LCD_CS: U1.89 (PB3); also elsewhere on the board
LCD_MOSI: U1.91 (PB5); also elsewhere on the board
LCD_SCK: U1.90 (PB4); also elsewhere on the board
M1_DIR: U1.29 (PA4); also elsewhere on the board
M1_STEP: U1.51 (PB12); also elsewhere on the board
M2_DIR: U1.30 (PA5); also elsewhere on the board
M2_STEP: U1.52 (PB13); also elsewhere on the board
M3_DIR: U1.31 (PA6); also elsewhere on the board
M3_STEP: U1.53 (PB14); also elsewhere on the board
M4_DIR: U1.32 (PA7); also elsewhere on the board
M4_STEP: U1.54 (PB15); also elsewhere on the board
M5_DIR: U1.33 (PC4); also elsewhere on the board
M5_STEP: U1.55 (PD8); also elsewhere on the board
MOTOR_E: U1.47 (PB10); also elsewhere on the board
MOTOR_X: U1.68 (PA9); also elsewhere on the board
MOTOR_Y: U1.86 (PD5); also elsewhere on the board
MOTOR_Z1: U1.23 (PA0); also elsewhere on the board
MOTOR_Z2: U1.63 (PC6); also elsewhere on the board
unnamed: J1.A5 (CC1), R2.2
unnamed: J1.B5 (CC2), R3.2
unnamed: R1.1, SW3.2 (B)
unnamed: C9.2, U1.49 (VCAP_1)
unnamed: C8.2, U1.73 (VCAP_2)
PROBE: U1.41 (PE10); also elsewhere on the board
SD_CD: U1.82 (PD1); also elsewhere on the board
SD_CLK: U1.80 (PC12); also elsewhere on the board
SD_CMD: U1.83 (PD2); also elsewhere on the board
SD_DAT0: U1.65 (PC8); also elsewhere on the board
SD_DAT1: U1.66 (PC9); also elsewhere on the board
SD_DAT2: U1.78 (PC10); also elsewhere on the board
SD_DAT3: U1.79 (PC11); also elsewhere on the board
SERVO: U1.40 (PE9); also elsewhere on the board
VBUS: J1.A4 (VBUS), J1.A9 (VBUS), J1.B4 (VBUS), J1.B9 (VBUS); also elsewhere on the board
XMAX_STOP: U1.1 (PE2); also elsewhere on the board
XMIN_STOP: U1.7 (PC13); also elsewhere on the board
YMAX_STOP: U1.2 (PE3); also elsewhere on the board
YMIN_STOP: U1.8 (PC14); also elsewhere on the board
ZMAX_STOP: U1.3 (PE4); also elsewhere on the board
ZMIN_STOP: U1.9 (PC15); also elsewhere on the board

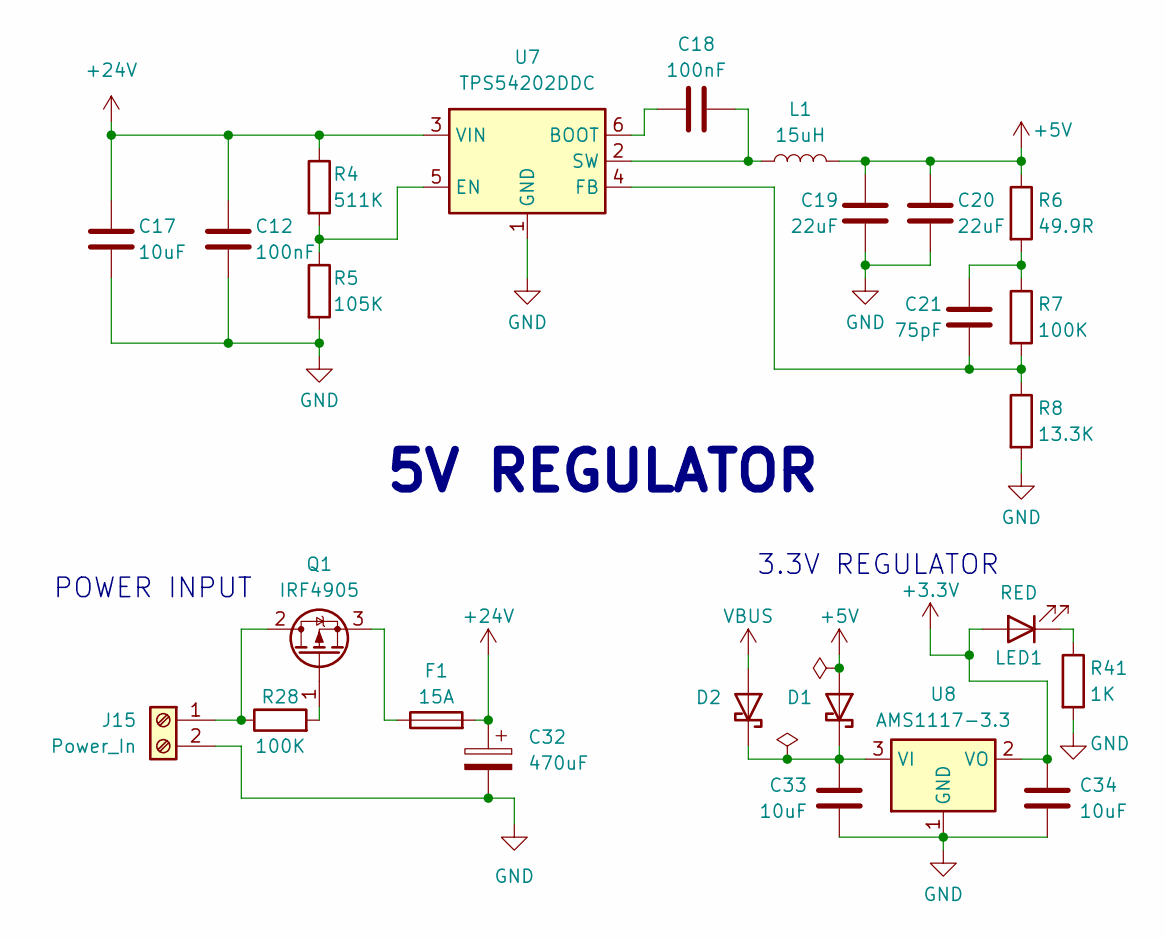
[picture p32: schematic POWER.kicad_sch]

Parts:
C12, C18: 100nF; C_0603_1608Metric
C17, C33, C34: 10uF; C_0805_2012Metric
C19, C20: 22uF; C_0805_2012Metric
C21: 75pF; C_0603_1608Metric
C32: 470uF; C_Elec_8x10.2
D1, D2: D_Schottky; D_0603_1608Metric
F1: 15A; Fuse_1206_3216Metric
J15: Power_In; TerminalBlock_Phoenix_MKDS-1,5-2-5.08_1x02_P5.08mm_Horizont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
L1: 15uH; L_Cenker_CKCS4030
LED1: RED; LED_0603_1608Metric
Q1: IRF4905; TRANS_IRF3205S
R4: 511K; R_0603_1608Metric
R5: 105K; R_0603_1608Metric
R6: 49.9R; R_0603_1608Metric
R7, R28: 100K; R_0603_1608Metric
R8: 13.3K; R_0603_1608Metric
R41: 1K; R_0603_1608Metric
U7: TPS54202DDC; SOT-23-6
U8: AMS1117-3.3; SOT-223-3_TabPin2

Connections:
+3.3V: C34.1, LED1.2 (A), U8.2 (VO); also elsewhere on the board
+5V: C19.1, C20.1, D1.2 (A), L1.2, R6.1; also elsewhere on the board
+24V: C12.1, C17.1, C32.1, F1.2, R4.1, U7.3 (VIN); also elsewhere on the board
GND: C12.2, C17.2, C19.2, C20.2, C32.2, C33.2, C34.2, J15.2, R5.2, R8.2, R41.2, U7.1 (GND), U8.1 (GND); also elsewhere on the board
unnamed: C21.1, R6.2, R7.1
unnamed: C33.1, D1.1 (K), D2.1 (K), U8.3 (VI)
unnamed: J15.1, Q1.2 (D), R28.1
unnamed: LED1.1 (K), R41.1
unnamed: Q1.1 (G), R28.2
unnamed: F1.1, Q1.3 (S)
unnamed: C18.1, U7.6 (BOOT)
unnamed: R4.2, R5.1, U7.5 (EN)
unnamed: C21.2, R7.2, R8.1, U7.4 (FB)
unnamed: C18.2, L1.1, U7.2 (SW)
VBUS: D2.2 (A); also elsewhere on the board

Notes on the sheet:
3.3V REGULATOR
POWER INPUT
5V REGULATOR

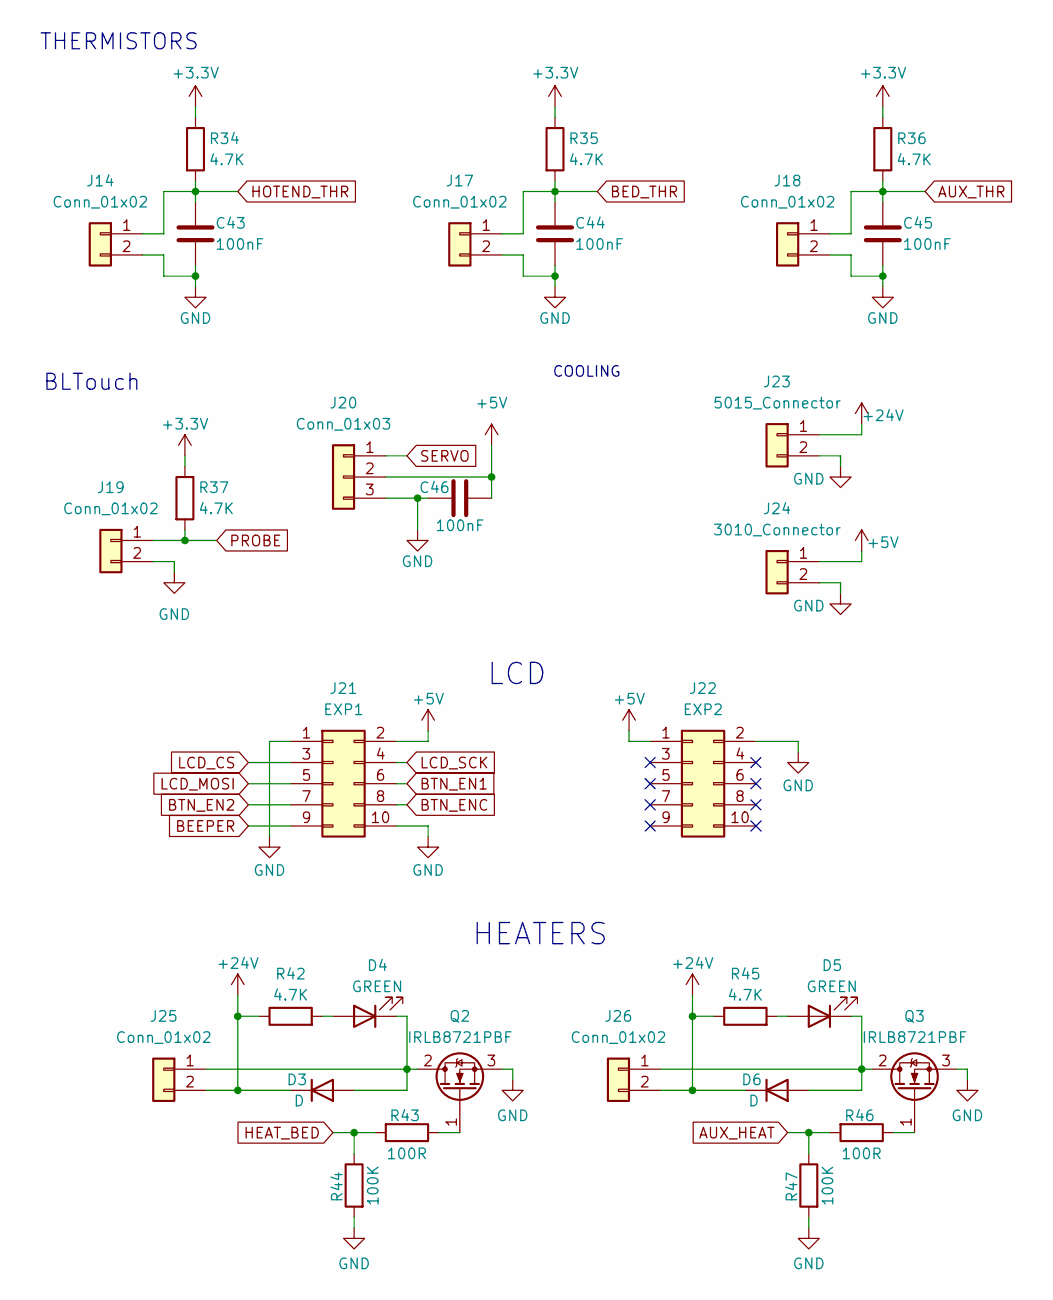
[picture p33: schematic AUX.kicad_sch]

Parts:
C43, C44, C45, C46: 100nF; C_0603_1608Metric
D3, D6: D; D_0603_1608Metric
D4, D5: GREEN; LED_0603_1608Metric
J14, J17, J18, J19, J25, J26: Conn_01x02; JST_XH_B2B-XH-AM_1x02_P2.50mm_Vertical
J20: Conn_01x03; JST_XH_B3B-XH-AM_1x03_P2.50mm_Vertical
J21: EXP1; IDC-Header_2x05_P2.54mm_Vertical
J22: EXP2; IDC-Header_2x05_P2.54mm_Vertical
J23: 5015_Connector; JST_XH_B2B-XH-AM_1x02_P2.50mm_Vertical
J24: 3010_Connector; JST_XH_B2B-XH-AM_1x02_P2.50mm_Vertical
Q2, Q3: IRLB8721PBF; TO252_AOS
R34, R35, R36, R37, R42, R45: 4.7K; R_0603_1608Metric
R43, R46: 100R; R_0603_1608Metric
R44, R47: 100K; R_0603_1608Metric

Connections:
+3.3V: R34.1, R35.1, R36.1, R37.1; also elsewhere on the board
+5V: C46.1, J20.2, J21.2, J22.1, J24.1; also elsewhere on the board
+24V: D3.1 (K), D6.1 (K), J23.1, J25.2, J26.2, R42.1, R45.1; also elsewhere on the board
AUX_HEAT: R46.2, R47.1; also elsewhere on the board
AUX_THR: C45.1, J18.1, R36.2; also elsewhere on the board
BED_THR: C44.1, J17.1, R35.2; also elsewhere on the board
BEEPER: J21.9; also elsewhere on the board
BTN_EN1: J21.6; also elsewhere on the board
BTN_EN2: J21.7; also elsewhere on the board
BTN_ENC: J21.8; also elsewhere on the board
GND: C43.2, C44.2, C45.2, C46.2, J14.2, J17.2, J18.2, J19.2, J20.3, J21.1, J21.10, J22.2, J23.2, J24.2, Q2.3 (S), Q3.3 (S), R44.2, R47.2; also elsewhere on the board
HEAT_BED: R43.2, R44.1; also elsewhere on the board
HOTEND_THR: C43.1, J14.1, R34.2; also elsewhere on the board
LCD_CS: J21.3; also elsewhere on the board
LCD_MOSI: J21.5; also elsewhere on the board
LCD_SCK: J21.4; also elsewhere on the board
unnamed: D3.2 (A), D4.1 (K), J25.1, Q2.2 (D)
unnamed: D4.2 (A), R42.2
unnamed: D5.2 (A), R45.2
unnamed: D5.1 (K), D6.2 (A), J26.1, Q3.2 (D)
unnamed: Q2.1 (G), R43.1
unnamed: Q3.1 (G), R46.1
PROBE: J19.1, R37.2; also elsewhere on the board
SERVO: J20.1; also elsewhere on the board

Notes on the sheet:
HEATERS
BLTouch
THERMISTORS
COOLING
LCD

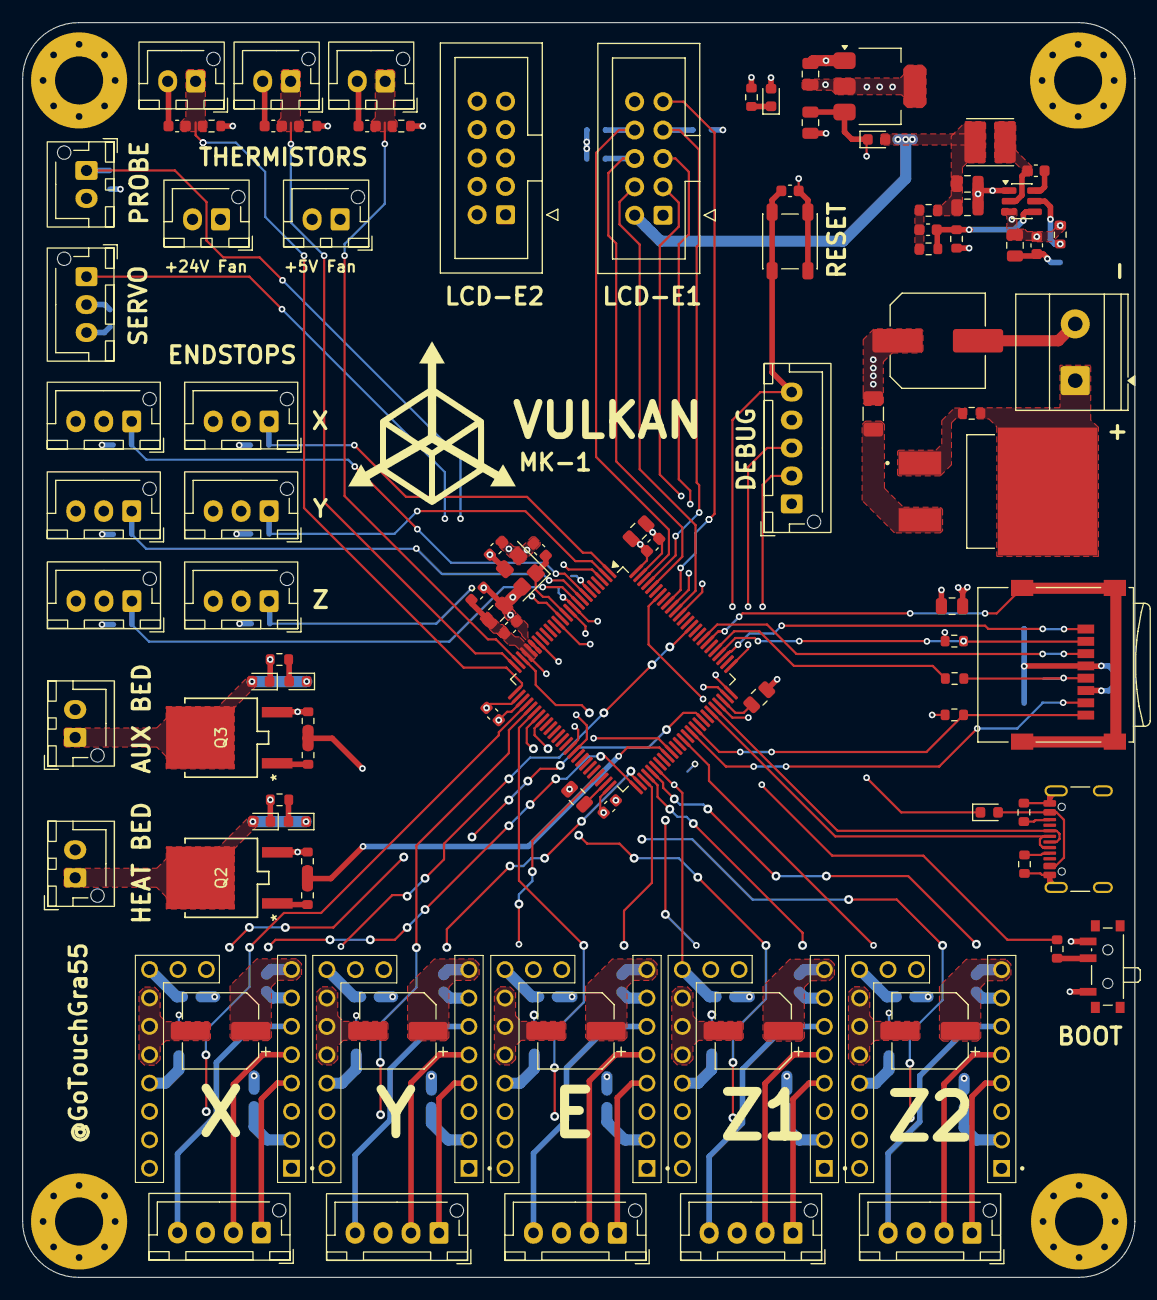
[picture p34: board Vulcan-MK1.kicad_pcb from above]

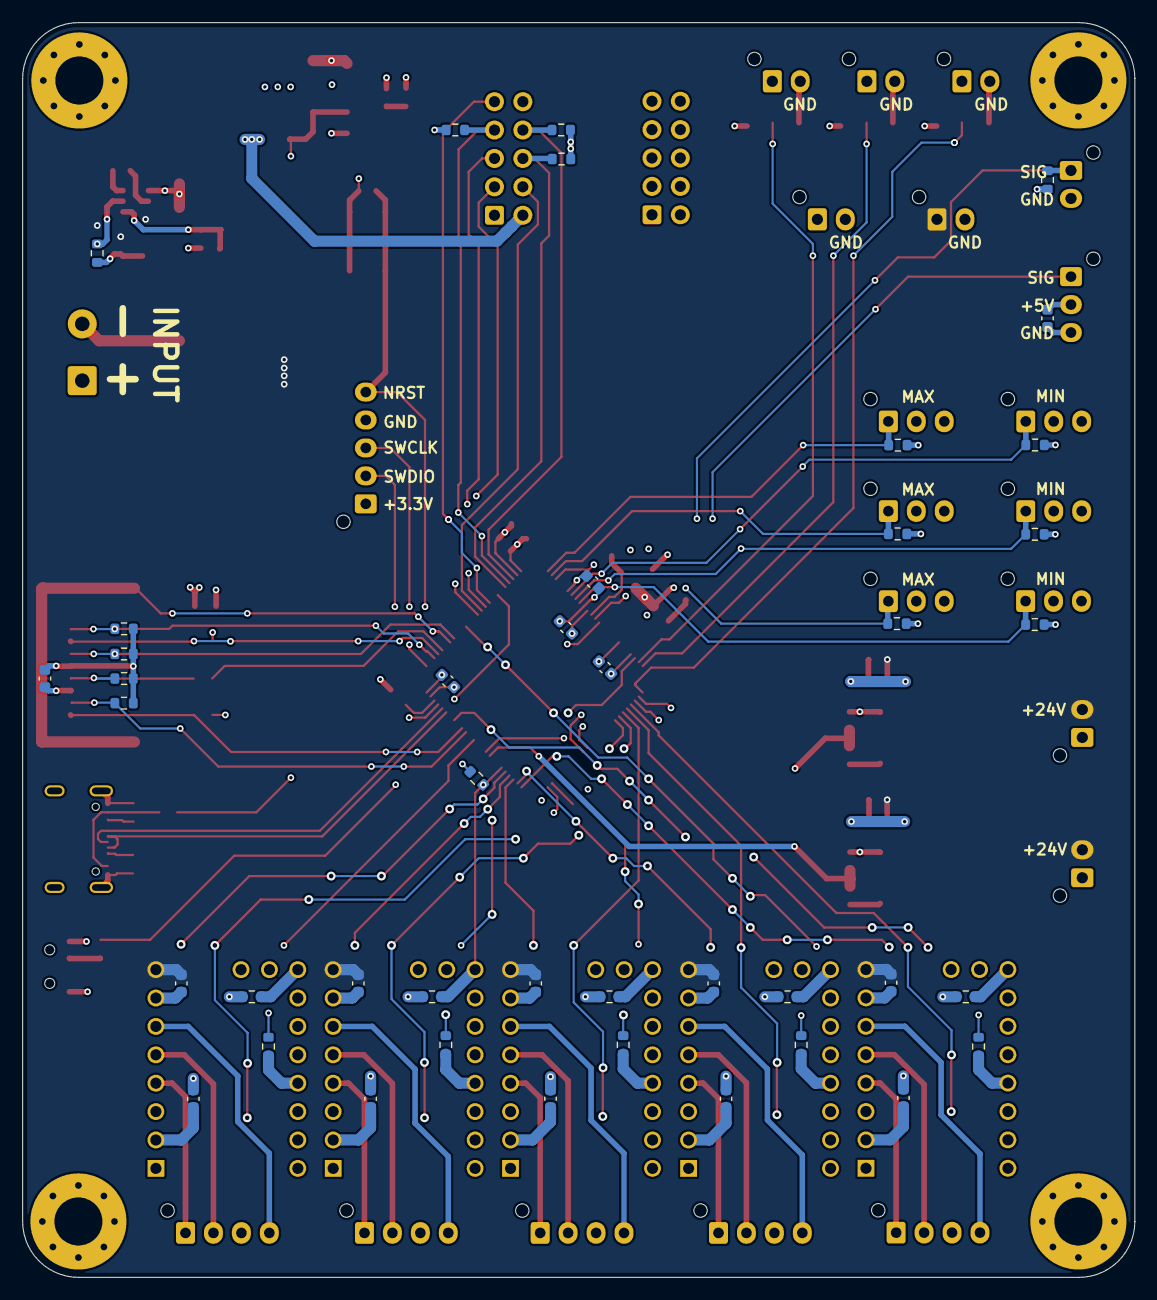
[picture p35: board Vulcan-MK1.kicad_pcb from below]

Board: 4 copper layers, 99.5 x 112.2 mm, 142 parts (42 on the bottom side), 109 nets.

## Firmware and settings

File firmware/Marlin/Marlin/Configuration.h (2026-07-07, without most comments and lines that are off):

#pragma once
#define CONFIGURATION_H_VERSION 02010206
#define STRING_CONFIG_H_AUTHOR "(none, default config)" // Who made the changes.
#define SHOW_BOOTSCREEN
  #define MOTHERBOARD BOARD_BLACK_STM32F407VE
#define SERIAL_PORT -1
#define BAUDRATE 250000
#define X_DRIVER_TYPE  TMC2209
#define Y_DRIVER_TYPE  TMC2209
#define Z_DRIVER_TYPE  TMC2209
#define Z2_DRIVER_TYPE TMC2209
#define E0_DRIVER_TYPE TMC2209
#define EXTRUDERS 1
#define DEFAULT_NOMINAL_FILAMENT_DIA 1.75
#define TEMP_SENSOR_0 1
#define TEMP_SENSOR_1 0
#define TEMP_SENSOR_2 0
#define TEMP_SENSOR_3 0
#define TEMP_SENSOR_4 0
#define TEMP_SENSOR_5 0
#define TEMP_SENSOR_6 0
#define TEMP_SENSOR_7 0
#define TEMP_SENSOR_BED 1
#define TEMP_SENSOR_PROBE 0
#define TEMP_SENSOR_CHAMBER 0
#define TEMP_SENSOR_COOLER 0
#define TEMP_SENSOR_BOARD 0
#define TEMP_SENSOR_REDUNDANT 0
#define DUMMY_THERMISTOR_998_VALUE  25
#define DUMMY_THERMISTOR_999_VALUE 100
#if TEMP_SENSOR_IS_MAX_TC(0)
  #define MAX31865_SENSOR_OHMS_0      100 // (Ω) Typically 100 or 1000 (PT100 or PT1000)
  #define MAX31865_CALIBRATION_OHMS_0 430 // (Ω) Typically 430 for Adafruit PT100; 4300 for Adafruit PT1000
#endif
#if TEMP_SENSOR_IS_MAX_TC(1)
  #define MAX31865_SENSOR_OHMS_1      100
  #define MAX31865_CALIBRATION_OHMS_1 430
#endif
#if TEMP_SENSOR_IS_MAX_TC(2)
  #define MAX31865_SENSOR_OHMS_2      100
  #define MAX31865_CALIBRATION_OHMS_2 430
#endif
#if HAS_E_TEMP_SENSOR
  #define TEMP_RESIDENCY_TIME         10  // (seconds) Time to wait for hotend to "settle" in M109
  #define TEMP_WINDOW                  1  // (°C) Temperature proximity for the "temperature reached" timer
  #define TEMP_HYSTERESIS              3  // (°C) Temperature proximity considered "close enough" to the target
#endif
#if TEMP_SENSOR_BED
  #define TEMP_BED_RESIDENCY_TIME     10  // (seconds) Time to wait for bed to "settle" in M190
  #define TEMP_BED_WINDOW              1  // (°C) Temperature proximity for the "temperature reached" timer
  #define TEMP_BED_HYSTERESIS          3  // (°C) Temperature proximity considered "close enough" to the target
#endif
#if TEMP_SENSOR_CHAMBER
  #define TEMP_CHAMBER_RESIDENCY_TIME 10  // (seconds) Time to wait for chamber to "settle" in M191
  #define TEMP_CHAMBER_WINDOW          1  // (°C) Temperature proximity for the "temperature reached" timer
  #define TEMP_CHAMBER_HYSTERESIS      3  // (°C) Temperature proximity considered "close enough" to the target
#endif
#if TEMP_SENSOR_REDUNDANT
  #define TEMP_SENSOR_REDUNDANT_SOURCE    E1  // The sensor that will provide the redundant reading.
  #define TEMP_SENSOR_REDUNDANT_TARGET    E0  // The sensor that we are providing a redundant reading for.
  #define TEMP_SENSOR_REDUNDANT_MAX_DIFF  10  // (°C) Temperature difference that will trigger a print abort.
#endif
#define HEATER_0_MINTEMP   5
#define HEATER_1_MINTEMP   5
#define HEATER_2_MINTEMP   5
#define HEATER_3_MINTEMP   5
#define HEATER_4_MINTEMP   5
#define HEATER_5_MINTEMP   5
#define HEATER_6_MINTEMP   5
#define HEATER_7_MINTEMP   5
#define BED_MINTEMP        5
#define CHAMBER_MINTEMP    5
#define HEATER_0_MAXTEMP 275
#define HEATER_1_MAXTEMP 275
#define HEATER_2_MAXTEMP 275
#define HEATER_3_MAXTEMP 275
#define HEATER_4_MAXTEMP 275
#define HEATER_5_MAXTEMP 275
#define HEATER_6_MAXTEMP 275
#define HEATER_7_MAXTEMP 275
#define BED_MAXTEMP      150
#define CHAMBER_MAXTEMP  60
#define HOTEND_OVERSHOOT 15   // (°C) Forbid temperatures over MAXTEMP - OVERSHOOT
#define BED_OVERSHOOT    10   // (°C) Forbid temperatures over MAXTEMP - OVERSHOOT
#define COOLER_OVERSHOOT  2   // (°C) Forbid temperatures closer than OVERSHOOT
#define PIDTEMP           // See the PID Tuning Guide at https://reprap.org/wiki/PID_Tuning
#define PID_MAX  255      // Limit hotend current while PID is active (see PID_FUNCTIONAL_RANGE below); 255=full current
#define PID_K1     0.95   // Smoothing factor within any PID loop
    #define DEFAULT_KP  22.20
    #define DEFAULT_KI   1.08
    #define DEFAULT_KD 114.00
#define MAX_BED_POWER 255 // limits duty cycle to bed; 255=full current
#define MAX_CHAMBER_POWER 255 // limits duty cycle to chamber heater; 255=full current
  #define PID_FUNCTIONAL_RANGE 10 // If the temperature difference between the target temperature and the actual temperature
#define PREVENT_COLD_EXTRUSION
#define EXTRUDE_MINTEMP 170
#define PREVENT_LENGTHY_EXTRUDE
#define EXTRUDE_MAXLENGTH 200
#define THERMAL_PROTECTION_HOTENDS // Enable thermal protection for all extruders
#define THERMAL_PROTECTION_BED     // Enable thermal protection for the heated bed
#define THERMAL_PROTECTION_CHAMBER // Enable thermal protection for the heated chamber
#define THERMAL_PROTECTION_COOLER  // Enable thermal protection for the laser cooling
#define USE_XMIN_PLUG
#define USE_YMIN_PLUG
#define USE_ZMIN_PLUG
#define ENDSTOPPULLUPS
#define X_MIN_ENDSTOP_INVERTING false // Set to true to invert the logic of the endstop.
#define Y_MIN_ENDSTOP_INVERTING false // Set to true to invert the logic of the endstop.
#define Z_MIN_ENDSTOP_INVERTING false // Set to true to invert the logic of the endstop.
#define I_MIN_ENDSTOP_INVERTING false // Set to true to invert the logic of the endstop.
#define J_MIN_ENDSTOP_INVERTING false // Set to true to invert the logic of the endstop.
#define K_MIN_ENDSTOP_INVERTING false // Set to true to invert the logic of the endstop.
#define U_MIN_ENDSTOP_INVERTING false // Set to true to invert the logic of the endstop.
#define V_MIN_ENDSTOP_INVERTING false // Set to true to invert the logic of the endstop.
#define W_MIN_ENDSTOP_INVERTING false // Set to true to invert the logic of the endstop.
#define X_MAX_ENDSTOP_INVERTING false // Set to true to invert the logic of the endstop.
#define Y_MAX_ENDSTOP_INVERTING false // Set to true to invert the logic of the endstop.
#define Z_MAX_ENDSTOP_INVERTING false // Set to true to invert the logic of the endstop.
#define I_MAX_ENDSTOP_INVERTING false // Set to true to invert the logic of the endstop.
#define J_MAX_ENDSTOP_INVERTING false // Set to true to invert the logic of the endstop.
#define K_MAX_ENDSTOP_INVERTING false // Set to true to invert the logic of the endstop.
#define U_MAX_ENDSTOP_INVERTING false // Set to true to invert the logic of the endstop.
#define V_MAX_ENDSTOP_INVERTING false // Set to true to invert the logic of the endstop.
#define W_MAX_ENDSTOP_INVERTING false // Set to true to invert the logic of the endstop.
#define Z_MIN_PROBE_ENDSTOP_INVERTING false // Set to true to invert the logic of the probe.
#define DEFAULT_AXIS_STEPS_PER_UNIT   { 80, 80, 400, 500 }
#define DEFAULT_MAX_FEEDRATE          { 300, 300, 5, 25 }
#define DEFAULT_MAX_ACCELERATION      { 3000, 3000, 100, 10000 }
#define DEFAULT_ACCELERATION          3000    // X, Y, Z and E acceleration for printing moves
#define DEFAULT_RETRACT_ACCELERATION  3000    // E acceleration for retracts
#define DEFAULT_TRAVEL_ACCELERATION   3000    // X, Y, Z acceleration for travel (non printing) moves
#define DEFAULT_EJERK    5.0  // May be used by Linear Advance
  #define JUNCTION_DEVIATION_MM 0.013 // (mm) Distance from real junction edge
  #define JD_HANDLE_SMALL_SEGMENTS    // Use curvature estimation instead of just the junction angle
#define Z_MIN_PROBE_USES_Z_MIN_ENDSTOP_PIN
#define NOZZLE_TO_PROBE_OFFSET { 10, 10, 0 }
#define PROBING_MARGIN 10
#define XY_PROBE_FEEDRATE (133*60)
#define Z_PROBE_FEEDRATE_FAST (4*60)
#define Z_PROBE_FEEDRATE_SLOW (Z_PROBE_FEEDRATE_FAST / 2)
#define Z_CLEARANCE_DEPLOY_PROBE   10 // (mm) Z Clearance for Deploy/Stow
#define Z_CLEARANCE_BETWEEN_PROBES  5 // (mm) Z Clearance between probe points
#define Z_CLEARANCE_MULTI_PROBE     5 // (mm) Z Clearance between multiple probes
#define Z_PROBE_LOW_POINT          -2 // (mm) Farthest distance below the trigger-point to go before stopping
#define Z_PROBE_OFFSET_RANGE_MIN -20
#define Z_PROBE_OFFSET_RANGE_MAX 20
#define X_ENABLE_ON 0
#define Y_ENABLE_ON 0
#define Z_ENABLE_ON 0
#define E_ENABLE_ON 0 // For all extruders
#define DISABLE_OTHER_EXTRUDERS   // Keep only the active extruder enabled
#define INVERT_X_DIR false
#define INVERT_Y_DIR true
#define INVERT_Z_DIR false
#define INVERT_E0_DIR false
#define INVERT_E1_DIR false
#define INVERT_E2_DIR false
#define INVERT_E3_DIR false
#define INVERT_E4_DIR false
#define INVERT_E5_DIR false
#define INVERT_E6_DIR false
#define INVERT_E7_DIR false
#define X_HOME_DIR -1
#define Y_HOME_DIR -1
#define Z_HOME_DIR -1
#define X_BED_SIZE 200
#define Y_BED_SIZE 200
#define X_MIN_POS 0
#define Y_MIN_POS 0
#define Z_MIN_POS 0
#define X_MAX_POS X_BED_SIZE
#define Y_MAX_POS Y_BED_SIZE
#define Z_MAX_POS 200
#define MIN_SOFTWARE_ENDSTOPS
  #define MIN_SOFTWARE_ENDSTOP_X
  #define MIN_SOFTWARE_ENDSTOP_Y
  #define MIN_SOFTWARE_ENDSTOP_Z
  #define MIN_SOFTWARE_ENDSTOP_I
  #define MIN_SOFTWARE_ENDSTOP_J
  #define MIN_SOFTWARE_ENDSTOP_K
  #define MIN_SOFTWARE_ENDSTOP_U
  #define MIN_SOFTWARE_ENDSTOP_V
  #define MIN_SOFTWARE_ENDSTOP_W
#define MAX_SOFTWARE_ENDSTOPS
  #define MAX_SOFTWARE_ENDSTOP_X
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

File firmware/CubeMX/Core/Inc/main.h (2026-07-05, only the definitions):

#define XMAX_STOP_Pin GPIO_PIN_2
#define XMAX_STOP_GPIO_Port GPIOE
#define YMAX_STOP_Pin GPIO_PIN_3
#define YMAX_STOP_GPIO_Port GPIOE
#define ZMAX_STOP_Pin GPIO_PIN_4
#define ZMAX_STOP_GPIO_Port GPIOE
#define XMIN_STOP_Pin GPIO_PIN_13
#define XMIN_STOP_GPIO_Port GPIOC
#define YMIN_STOP_Pin GPIO_PIN_14
#define YMIN_STOP_GPIO_Port GPIOC
#define ZMIN_STOP_Pin GPIO_PIN_15
#define ZMIN_STOP_GPIO_Port GPIOC
#define MOTOR_Z1_Pin GPIO_PIN_0
#define MOTOR_Z1_GPIO_Port GPIOA
#define HOTEND_THR_Pin GPIO_PIN_1
#define HOTEND_THR_GPIO_Port GPIOA
#define BED_THR_Pin GPIO_PIN_2
#define BED_THR_GPIO_Port GPIOA
#define AUX_THR_Pin GPIO_PIN_3
#define AUX_THR_GPIO_Port GPIOA
#define MX_DIR_Pin GPIO_PIN_4
#define MX_DIR_GPIO_Port GPIOA
#define MY_DIR_Pin GPIO_PIN_5
#define MY_DIR_GPIO_Port GPIOA
#define ME_DIR_Pin GPIO_PIN_6
#define ME_DIR_GPIO_Port GPIOA
#define MZ1_DIR_Pin GPIO_PIN_7
#define MZ1_DIR_GPIO_Port GPIOA
#define SERVO_Pin GPIO_PIN_9
#define SERVO_GPIO_Port GPIOE
#define PROBE_Pin GPIO_PIN_10
#define PROBE_GPIO_Port GPIOE
#define MOTOR_E_Pin GPIO_PIN_10
#define MOTOR_E_GPIO_Port GPIOB
#define MX_STEP_Pin GPIO_PIN_12
#define MX_STEP_GPIO_Port GPIOB
#define MY_STEP_Pin GPIO_PIN_13
#define MY_STEP_GPIO_Port GPIOB
#define ME_STEP_Pin GPIO_PIN_14
#define ME_STEP_GPIO_Port GPIOB
#define MZ1_STEP_Pin GPIO_PIN_15
#define MZ1_STEP_GPIO_Port GPIOB
#define MZ2_STEP_Pin GPIO_PIN_8
#define MZ2_STEP_GPIO_Port GPIOD
#define DR_EN_Pin GPIO_PIN_9
#define DR_EN_GPIO_Port GPIOD
#define HEAT_BED_Pin GPIO_PIN_12
#define HEAT_BED_GPIO_Port GPIOD
#define AUX_HEAT_Pin GPIO_PIN_13
#define AUX_HEAT_GPIO_Port GPIOD
#define MOTOR_Z2_Pin GPIO_PIN_6
#define MOTOR_Z2_GPIO_Port GPIOC
#define MOTOR_X_Pin GPIO_PIN_9
#define MOTOR_X_GPIO_Port GPIOA
#define SD_CD_Pin GPIO_PIN_1
#define SD_CD_GPIO_Port GPIOD
#define MOTOR_Y_Pin GPIO_PIN_5
#define MOTOR_Y_GPIO_Port GPIOD
#define LCD_CS_Pin GPIO_PIN_3
#define LCD_CS_GPIO_Port GPIOB
#define LCD_SCK_Pin GPIO_PIN_4
#define LCD_SCK_GPIO_Port GPIOB
#define LCD_MOSI_Pin GPIO_PIN_5
#define LCD_MOSI_GPIO_Port GPIOB
#define BEEPER_Pin GPIO_PIN_6
#define BEEPER_GPIO_Port GPIOB
#define BTN_EN1_Pin GPIO_PIN_9
#define BTN_EN1_GPIO_Port GPIOB
#define BTN_EN2_Pin GPIO_PIN_0
#define BTN_EN2_GPIO_Port GPIOE
#define BEN_ENC_Pin GPIO_PIN_1
#define BEN_ENC_GPIO_Port GPIOE

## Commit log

2026-07-05 Add firmware files
    [Configuration.h, Configuration_adv.h, esp32.csv]
2026-07-07 Add pins and bug fix
    [Configuration.h]
2026-07-11 Add 3d files
    [NOT-618-Bearing Mount.step, NOT-618-Bearing Mount.stl, NOT-618-Bed Adapter(x4).step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]
2026-07-11 Add kicad files
    [AUX.kicad_sch, Drivers.kicad_sch, MCU.kicad_sch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]
2026-07-12 Format Bill of Materials and add author section
    Updated the Bill of Materials with dollar signs and added author section.
2026-07-26 Update files for smaller rods
    [NOT-618 - Bearing Mount.step, NOT-618 - Bearing Mount.stl, NOT-618 - Bed Adapter (1).step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]
2026-07-26 Update README with firmware flashing instructions
    Added instructions for flashing firmware and updated BOM costs.
2026-08-07 Add BOM file
    [BOM.csv]
2026-09-21 Add changes
    [AUX.kicad_sch, BOM.csv, Memory.kicad_sch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]

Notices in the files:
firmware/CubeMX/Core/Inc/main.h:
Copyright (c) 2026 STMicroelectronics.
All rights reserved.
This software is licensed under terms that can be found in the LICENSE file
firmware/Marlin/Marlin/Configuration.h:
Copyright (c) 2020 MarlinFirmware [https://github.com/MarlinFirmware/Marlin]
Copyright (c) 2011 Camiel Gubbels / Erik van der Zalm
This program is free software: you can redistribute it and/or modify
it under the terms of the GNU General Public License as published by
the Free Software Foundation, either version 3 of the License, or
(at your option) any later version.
